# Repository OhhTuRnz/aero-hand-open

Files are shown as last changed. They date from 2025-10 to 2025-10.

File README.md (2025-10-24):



## License — TL;DR

- You **can** integrate Aero Hand units you purchase from TetherIA into **commercial robots and products** you sell.
- **Software (firmware & SDK):** Apache-2.0 — commercial use OK (with notices).
- **Design files (CAD/STEP/STL, drawings, BOM, docs):** CC BY‑NC‑SA 4.0 — **non‑commercial** only; derivatives must use the same license with attribution.
- Want to **manufacture/print parts** or **make your own hands** from our design files for commercial use (spares, kits, or clones)? → **Commercial manufacturing license required**.
- **Commercial licensing & volume buys:** see **LICENSE.md** (or email us at contact@tetheria.ai).

See [**LICENSE.md**](LICENSE.md) for definitions, examples, and contact details.

© 2025 TetherIA Inc. All rights reserved.

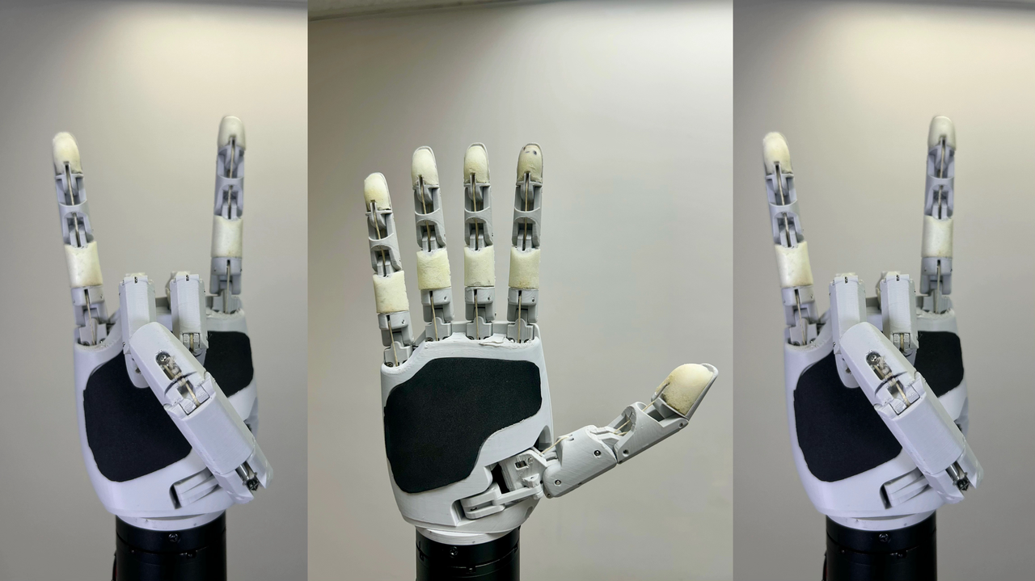
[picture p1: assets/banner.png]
Aero Hand Overview


Aero Hand Open is an **open-source**, **tendon-driven** robotic hand designed and developed by TetherIA for dexterous manipulation research. Unlike expensive proprietary solutions, this hand focuses on **simplicity**, **reliability**, and **accessibility** by using standard 3D printing and off-the-shelf electronic components.

Each joint is optimized for mechanical efficiency through tendon actuation, enabling smooth and natural motion while maintaining a **lightweight** and **compact** design, making it perfect for research labs, educational institutions, and robotics enthusiasts who need an **affordable** yet **capable** manipulation platform.

> **📚 Learn More:** https://docs.tetheria.ai/  
> **🛒 Shop:** https://shop.tetheria.ai/

# Aero Hand Open features:
- 7 DoFs robotic hand with 5 fingers (16 joints in total)
- Tendon-driven architecture for smooth and natural motion
- Fully 3D-printed structure, modular and easy to assemble
- Lightweight design — **389 g**
- Affordable — complete kit for **$314 USD**
- Open-source hardware and firmware
- Independent Python SDK, and compatible with ESP32 and ROS2 systems

# Overview:

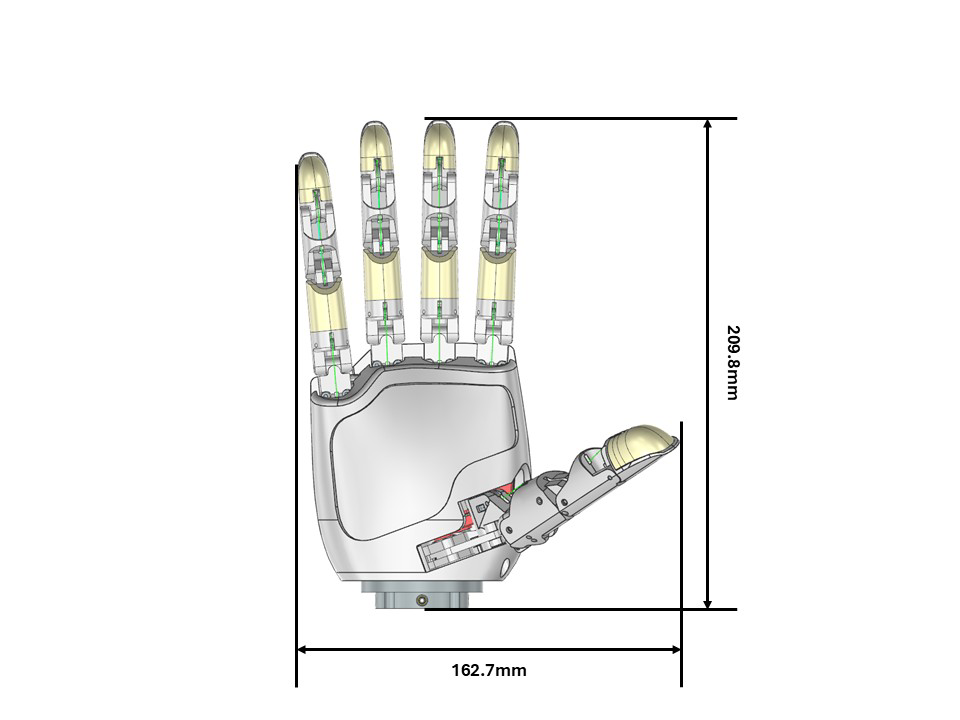
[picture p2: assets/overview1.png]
Overview1


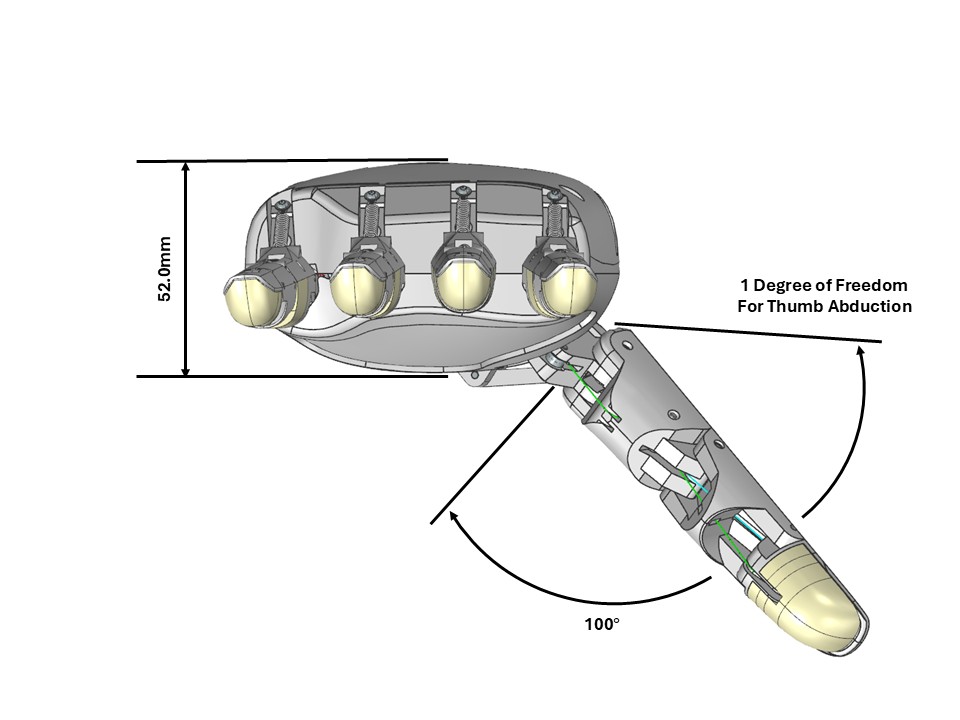
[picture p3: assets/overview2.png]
Overview1


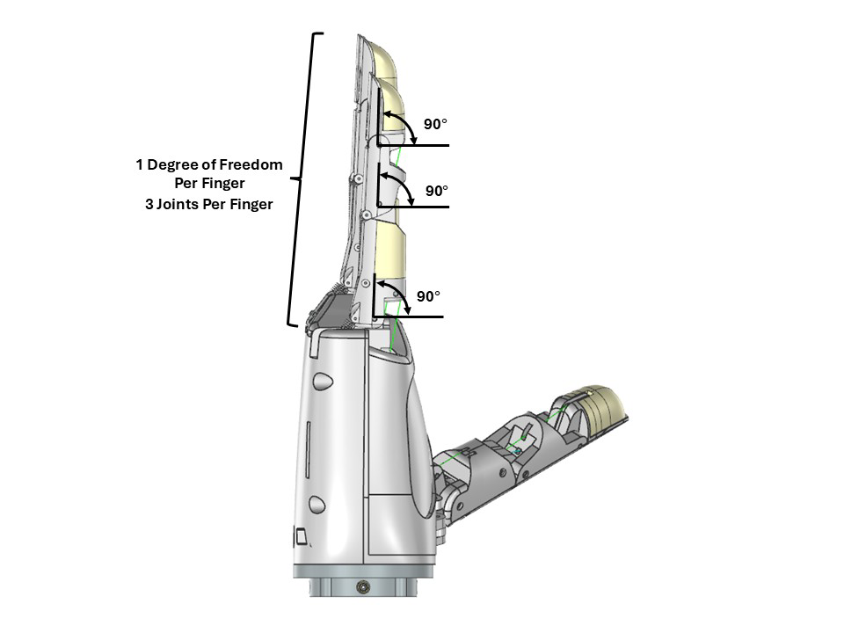
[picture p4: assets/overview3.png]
Overview1


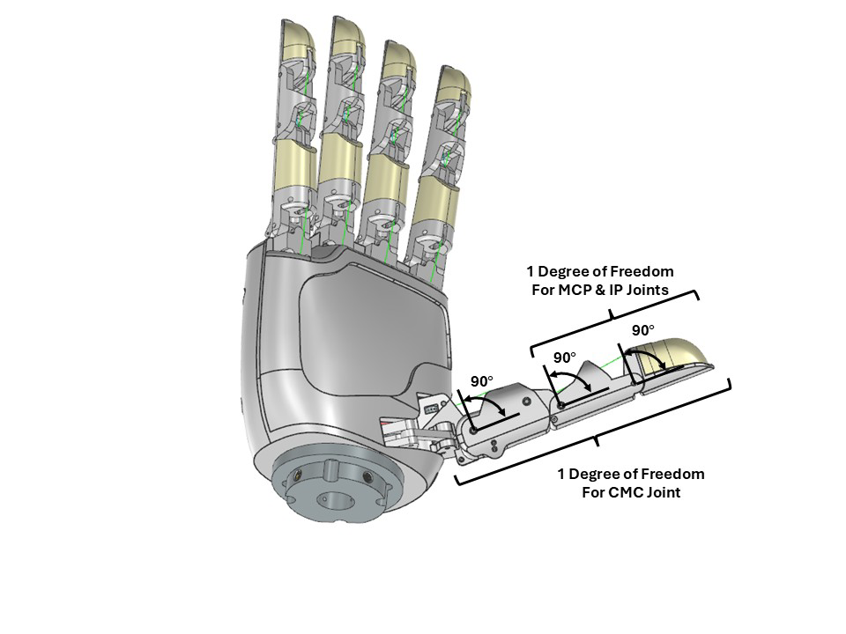
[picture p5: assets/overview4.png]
Overview1


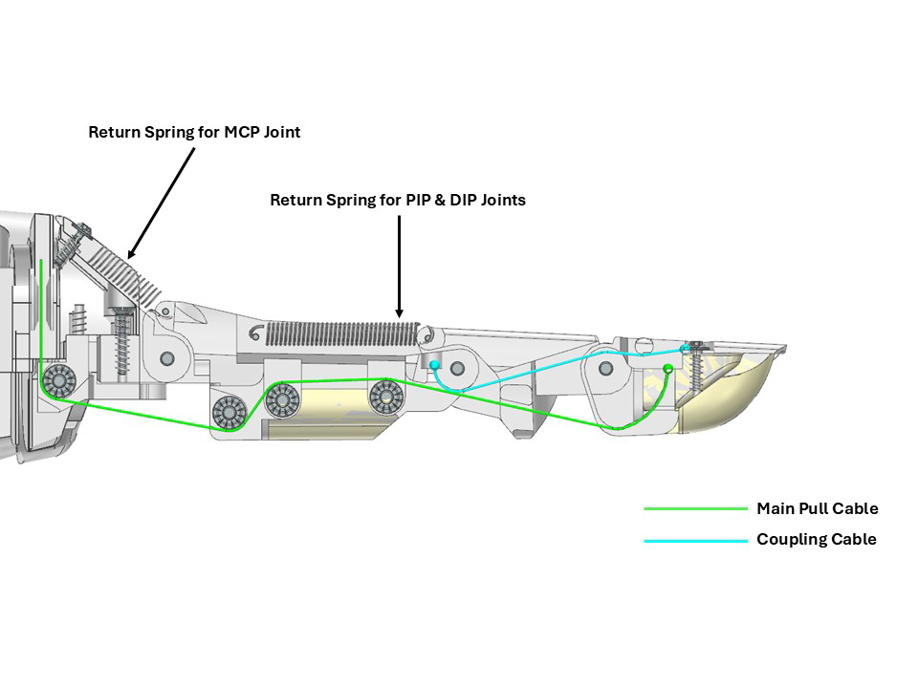
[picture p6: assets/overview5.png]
Overview1


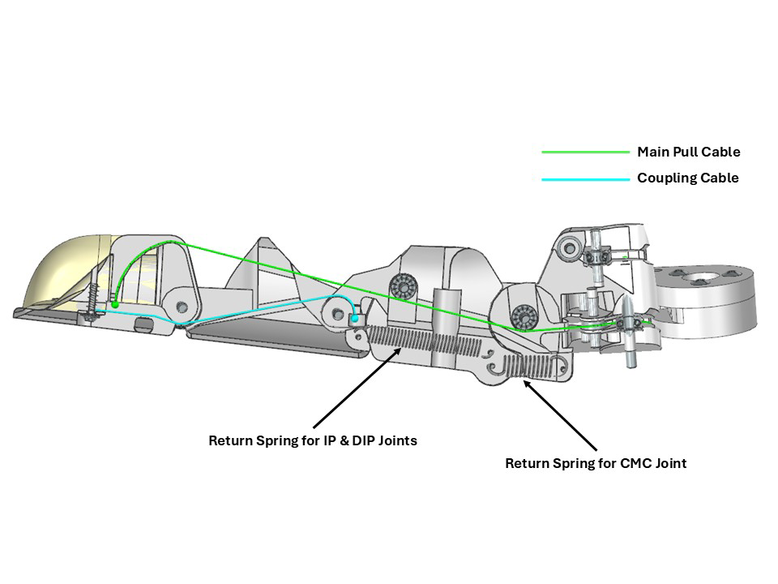
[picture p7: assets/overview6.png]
Overview1


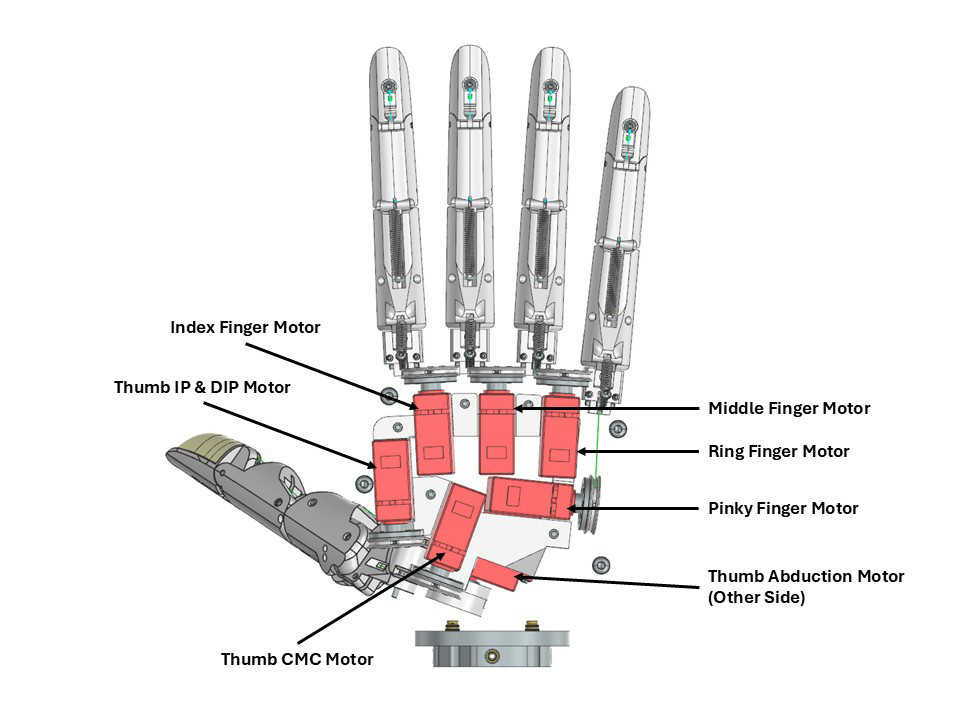
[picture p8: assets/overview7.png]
Overview1


# Table of Contents:
- Resources
  - Bill of Materials (BOM)
  - CAD Files and 3D Models
  - PCB Design
  - Assembly Guide
  - Hardware Setup
  - SDK
  - ROS2 and Teleoperation
- Disclaimer
- Project Updates & Community
  - Updates History
  - FAQ
  - Contact

# Resources
## Bill of Materials (BOM)
The complete list of components required to build Aero Hand Open can be found here:

 [👉 Aero Hand Open – Bill of Materials](./hardware/Assembly/BOM.csv)

This document includes all mechanical, electronic, and printed parts — such as motors, tendons, bearings, fasteners, and 3D-printed components.

Each item is listed with its part number, vendor, quantity, and estimated cost to help you easily source or substitute parts.

## CAD Files and 3D Models
All CAD and 3D model files of Aero Hand Open are available in the [CAD](./hardware/CAD).

You can find both STEP and STL files for modification and direct 3D printing.

> CAD Files Notes:
> The absolute origin of the full assembly is at the MCP joint of middle finger

For quick setup, we also provide a “One-Click Print Pack”, which contains all parts with pre-oriented build angles optimized for print strength, surface quality, and minimal support usage.

Simply load the files into your slicer and start printing — no additional rotation or manual adjustment is required.

Printing Notes:
- Suggested Printer: Bambau Lab X1C/P1S
- Recommended material: PLA (for stiffness and dimensional accuracy)
- Suggested layer height: 0.2 mm (Nozzle Diameter 0.4mm)
- Support: Autogenerate is fine
- The hand design is fully modular — individual fingers can be printed and replaced independently
- Other information can be found in Assembly Documents

An online Onshape model is also available for quick viewing and part reference:

[👉 Aero Hand Open – Onshape Document](https://cad.onshape.com/documents/afc7e0ca7eb6d412ec8771f8/w/bc4d7e45e17e23d622d2bad2/e/1e3862db4d4df7d9dca6f286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)

## Assembly Guide
The step-by-step assembly instructions for Aero Hand Open are provided in the following document:

[👉 Aero Hand Open – Assembly Guide](https://docs.tetheria.ai/docs/assembly)

This guide covers the entire build process, from mounting the actuators to routing the tendons and connecting the electronics. Each finger module can be assembled independently and attached to the palm afterward, allowing easier maintenance and quick replacement.

## PCB Design
The Aero Hand Open consists of two custom PCB boards: Board A and Board B. All design files - including Gerber files, KiCad project files, BOM, and CPL - are available in [PCB folder](./hardware/PCB/)

#### Board A
 - Features 8 Molex connectors for connecting all servos in the hand.
 - Includes a JST connector P3.96mm for outer wiring and fitting inside the hand enclosure.
 - Designed for compact integration and reliable servo connectivity.
#### Board B
 - Includes a JST connector and one Molex connector for testing individual servos and debugging.
 - Features a terminal block to connect a regulated 6V, 10A power supply for the servos.
 - Hosts the ESP32-S3 microcontroller with a USB-C port for:
      - Powering the ESP32-S3
      - Communication between PC and ESP32-S3
      - Interfacing with the hand
 - Board B is essential for diagnostics and safe power delivery.

## Hardware Setup
**Buy our custom PCBs** (described above) from our [website](https://shop.tetheria.ai/products/pcbs) for a **plug-and-play solution**. 

✅ **Benefits:**
- **Zero soldering required** - just plug and play
- **Professional quality** - tested and verified PCBs
- **Self-explanatory connections** - cable connections are straightforward
- **Maximum reliability** - optimized for all motor currents
- **Time-saving** - get your hand running in minutes, not hours

🔗 **[Order PCBs Now →](https://shop.tetheria.ai/products/pcbs)**

For more info please refer to here https://docs.tetheria.ai/docs/hardware_setup

## Software SDK
We provide basic introduction and usage here. A detailed introduction to SDK is included in the following folder.

 👉 [`sdk/README.md`](sdk/README.md)

### Installation: 
📦 Install via pip
```bash
pip install aero-hand-sdk
```
     
🧩 Install from source (editable mode)
Clone the repository to your local machine:
```bash
git clone https://github.com/TetherIA/aero-open-sdk.git
```
     
Navigate to the cloned repository directory:
```bash
cd aero-open-sdk
```

Install the package in editable mode:
```bash
pip install -e .
```

### One-Time Setup
When setting up your hand for the first time, our setup GUI helps you configure motor IDs and test motor connections.
After installation, launch the Setup GUI with:
```bash
aero-hand-gui
```

This provides an interactive interface to configure your hand.

### Sequencing Demo
The Sequencing Demo demonstrates how different finger motions can be combined into continuous, pre-defined sequences.

This script enables users to perform complex gestures — such as pinching, opening the palm, or making a peace sign — by automatically coordinating joint movements in a timed sequence.

You can find the example code in the SDK example folder. 

👉 [`sdk/examples/`](sdk/examples)

Once the SDK is installed and the serial port has been configured, you can run any of the example scripts directly using Python as follows:

```bash
python run_sequence.py
```
[🎥 Watch the demo](assets/sequence_square.mp4)

## ROS2 and Teleoperation
The Aero Hand Open integrates seamlessly with ROS2 humble for advanced robotics applications. The ROS2 package includes:

- **URDF models** for accurate robot simulation and visualization
- **Launch files** for easy integration with existing ROS2 workflows  
- **Teleoperation support** for real-time hand control
- **RViz configuration** for 3D visualization and debugging

Refer to the [`ros2/`](./ros2/) folder for complete setup instructions and examples.

# Disclaimer
Aero Hand Open is an open-source research prototype intended for educational and experimental purposes only.

While every effort has been made to ensure build accuracy and functionality, this design has not been validated for prolonged or heavy-duty use.

Users should exercise caution when assembling, operating, or modifying this device. TetherIA Inc. and its contributors shall not be held liable for any personal injury, property damage, or other losses resulting from the use, misuse, or modification of this design. By using this project, you acknowledge and accept full responsibility for any associated risks.

Important Notes:
- 3D-printed parts may exhibit tolerance variations depending on printer and material settings.
- The tendon-driven mechanism requires regular tension adjustment to maintain consistent motion.
- Overloading the joints or applying excessive torque may cause mechanical deformation or servo damage.
- This project is provided as is, without any warranty or guarantee of fitness for a particular purpose.

We encourage the community to share improvements, feedback, and modifications through pull requests or GitHub discussions.

Your contributions will help make Aero Hand Open more reliable and versatile for the entire robotics community.

# Project Updates & Community
## Updates History
- 10/24/2025
  - Release hardware and ROS2 packages
- 10/13/2025
  - Product launched on all platforms

## FAQ
Q1: Can I modify and redistribute the Aero Hand Open design?

A: Yes, as long as it complies with the CC BY-NC-SA 4.0 license (non-commercial, attribution required, share alike).

Q2: What 3D printer and material do you recommend?

A: Any FDM printer with a ≥200×200 mm bed. PLA works best for strength and dimensional accuracy.

## Contact
For questions, feedback, or collaboration inquiries, please reach out to us through the following channels:

 🛒 Shop: [Aero Hand Open – TetherIA Store](https://shop.tetheria.ai/) 

 📚 Docs: [TetherIA Docs](https://docs.tetheria.ai/)

 📧 Email: support@tetheria.ai

 🌐 Website: [tetheria.ai](http://tetheria.ai)

 🐙 GitHub: [TetherIA](https://github.com/TetherIA)

 💬 Discord: [TetherIA Discord Channel](http://discord.gg/ZQKWK7NebQ)

  🐦 X/Twitter: [TetherIA X/Twitter Account](https://x.com/TetherIA_ai)

  📺 YouTube: [TetherIA YouTube Account](https://www.youtube.com/@TetherIA_ai)

  💼 LinkedIn: [TetherIA LinkedIn Account](https://www.linkedin.com/company/tetheria/)

We welcome discussions, contributions, and new ideas from the community.

If you have improvements to the design, firmware, or control software, feel free to open a Pull Request or start a Discussion on GitHub.

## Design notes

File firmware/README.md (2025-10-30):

<p align="center">
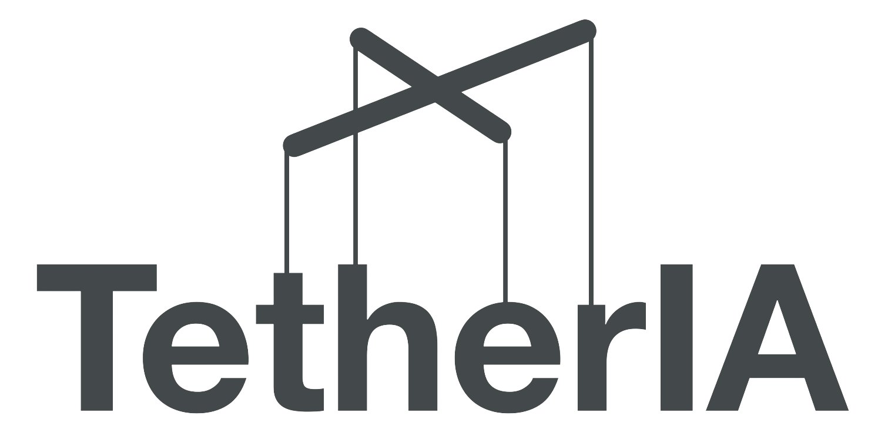
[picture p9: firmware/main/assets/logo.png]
Aero Hand Open by TetherIA
  
  <br/><br/>
</p>

# Aero Hand Open Firmware v0.1.0 — README

A reference guide for building, flashing, using, and extending the **Aero Hand Open** firmware that runs on an ESP32‑S3 (Seeed Studio XIAO ESP32S3) and drives Feetech smart servos - Feetech HLS3606M.

**Note:** If you do not need advanced control over the actuator, you only need the `.bin` file from this repository. You can download the bin files from the `main/bin` folder , and use the GUI to upload them to your device. We recommend using the [aero-open-sdk](https://github.com/TetherIA/aero-open-sdk) to upload the firmware by running the `aero-open-gui`.

---

## Table of Contents
- [1) Overview](#1-overview)
- [2) Repository Layout](#2-repository-layout)
- [3) Hardware & Software Requirements](#3-hardware--software-requirements)
- [4) Quick Start](#4-quick-start)
- [5) Firmware Architecture](#5-firmware-architecture)
- [6) Selecting LEFT vs RIGHT Hand at Build Time](#6-selecting-left-vs-right-hand-at-build-time)
- [7) Serial Protocol](#7-serial-protocol)
- [8) Homing Behavior](#8-homing-behavior)
- [9) Extending the Firmware with a New Command](#9-extending-the-firmware-with-a-new-command)
- [10) Code Reference (quick lookup)](#10-code-reference-quick-lookup)
- [11) Safety & Best Practices](#11-safety--best-practices)
- [12) Troubleshooting](#12-troubleshooting)
- [13) Contribution](#13-contribution)
- [14) License](#14-license)
- [15) Support](#15-Support)

---

## 1) Overview

The firmware exposes a compact **fixed 16‑byte binary serial protocol** so a host PC can command finger positions and query telemetry while the device handles **homing**, calibration, and basic safety on‑board.

**Major components**
- **`firmware_v0.1.0.ino`** — Main sketch: hardware init, serial command parser, periodic tasks, and command handlers.
- **`HandConfig.h`** — **Defines LEFT_HAND or RIGHT_HAND** (build‑time) to select the correct baseline calibration and channel directions.
- **`Homing.h` / `Homing.cpp`** — Implements the **homing** routine (`HOMING_start()` / `HOMING_isBusy()`), plus baseline tables and helpers.

**Servos / channels** (7):
1. Thumb CMC Abduction
2. Thumb CMC Flexion
3. Thumb Tendon (thumb curl/tendon drive)
4. Index
5. Middle
6. Ring
7. Pinky

---

## 2) Repository Layout

```
/main
  ├─ firmware_v0.1.0.ino          # main sketch
  ├─ HandConfig.h                 # LEFT_HAND / RIGHT_HAND selection
  ├─ Homing.h                     # homing API + ServoData type
  ├─ Homing.cpp                   # homing implementation + baselines
  └─ (libraries as needed)
```

---

## 3) Hardware & Software 

- **MCU**: Seeed Studio XIAO ESP32‑S3 (8 MB flash recommended)
- **Servos**: Feetech HLS3606M (IDs mapped to the 7 joints)
- **Power**: Power Servo rail at 6 with adequate current (Max Current up to 10A) , separate from USB 5 V
- **Tools**: [Arduino IDE](https://www.arduino.cc/en/software/) or PlatformIO.

---

## 4) Quick Start

### A. Select LEFT or RIGHT hand
In `HandConfig.h`, **define exactly one** of the following macros, or pass a build flag (see §6):
```c++
// #define LEFT_HAND
#define RIGHT_HAND
```

The choice selects the correct baseline calibration table at build time.

### B. Build & Flash
- **PlatformIO**: On your Visual Studio Code, Once you install the platformIO, Restart your Visual studio Code. You will now see a icon on the left for PlatformIO as below.
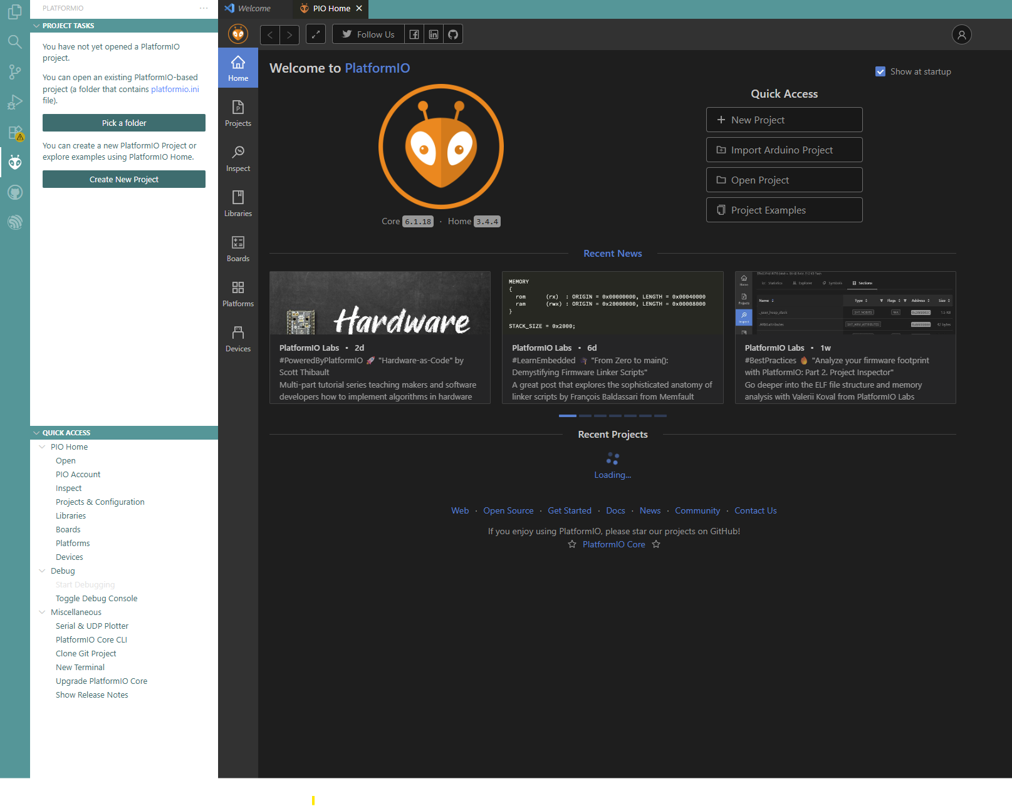
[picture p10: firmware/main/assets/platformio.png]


Once You Reach here, You can press on create a new project . Once you click , It will ask you to enter the Project name and settings, Feel free to choose your desired location and project name,But keep Framework as Arduino and Board as Seeed Studio XIAO ESP32S3.

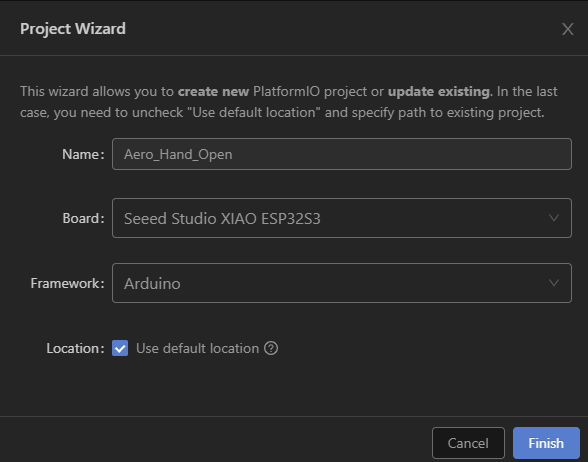
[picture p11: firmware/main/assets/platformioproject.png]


Now it will open the folder with a `platformio.ini` file. You might need to add a location where you have the FTServo library.  You can use build_flags to build it for the right or left hand. You need to copy paste over the ``firmware_v0.1.0.ino`` file in the ``main.cpp`` and you also need the header and cpp files under src directory as in the below given image.

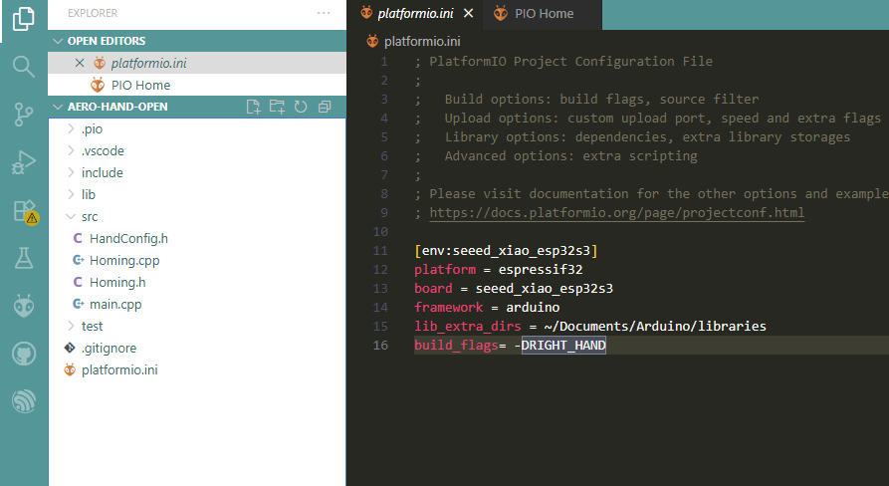
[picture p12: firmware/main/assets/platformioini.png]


Now, You again need to go back to that build and upload page by pressing the PlatformIO icon. Here you can see an upload , Once you press the upload button, It should compile your files and upload it.
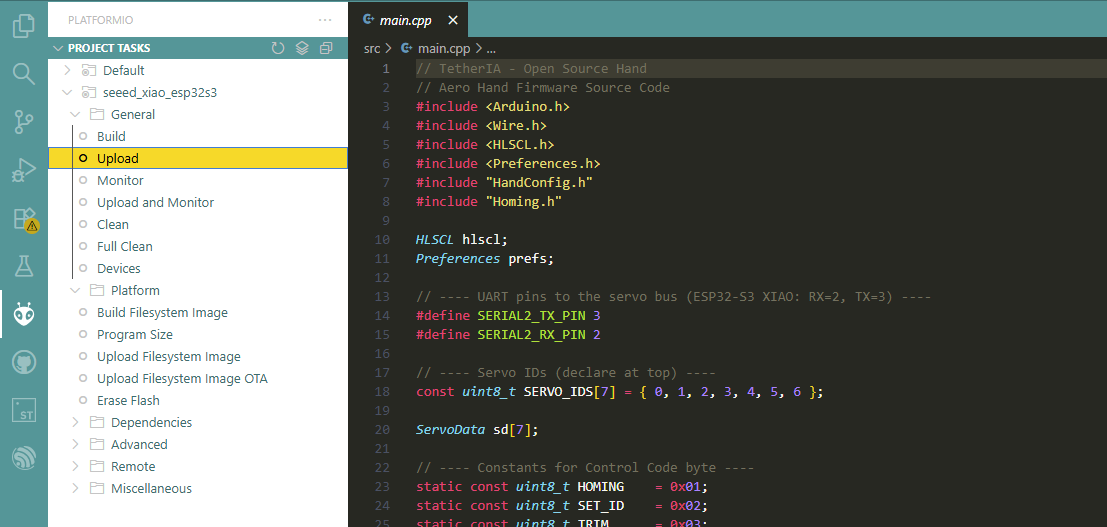
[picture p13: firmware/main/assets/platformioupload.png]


On successful upload, You will see some logs in your terminal window like in the image below.
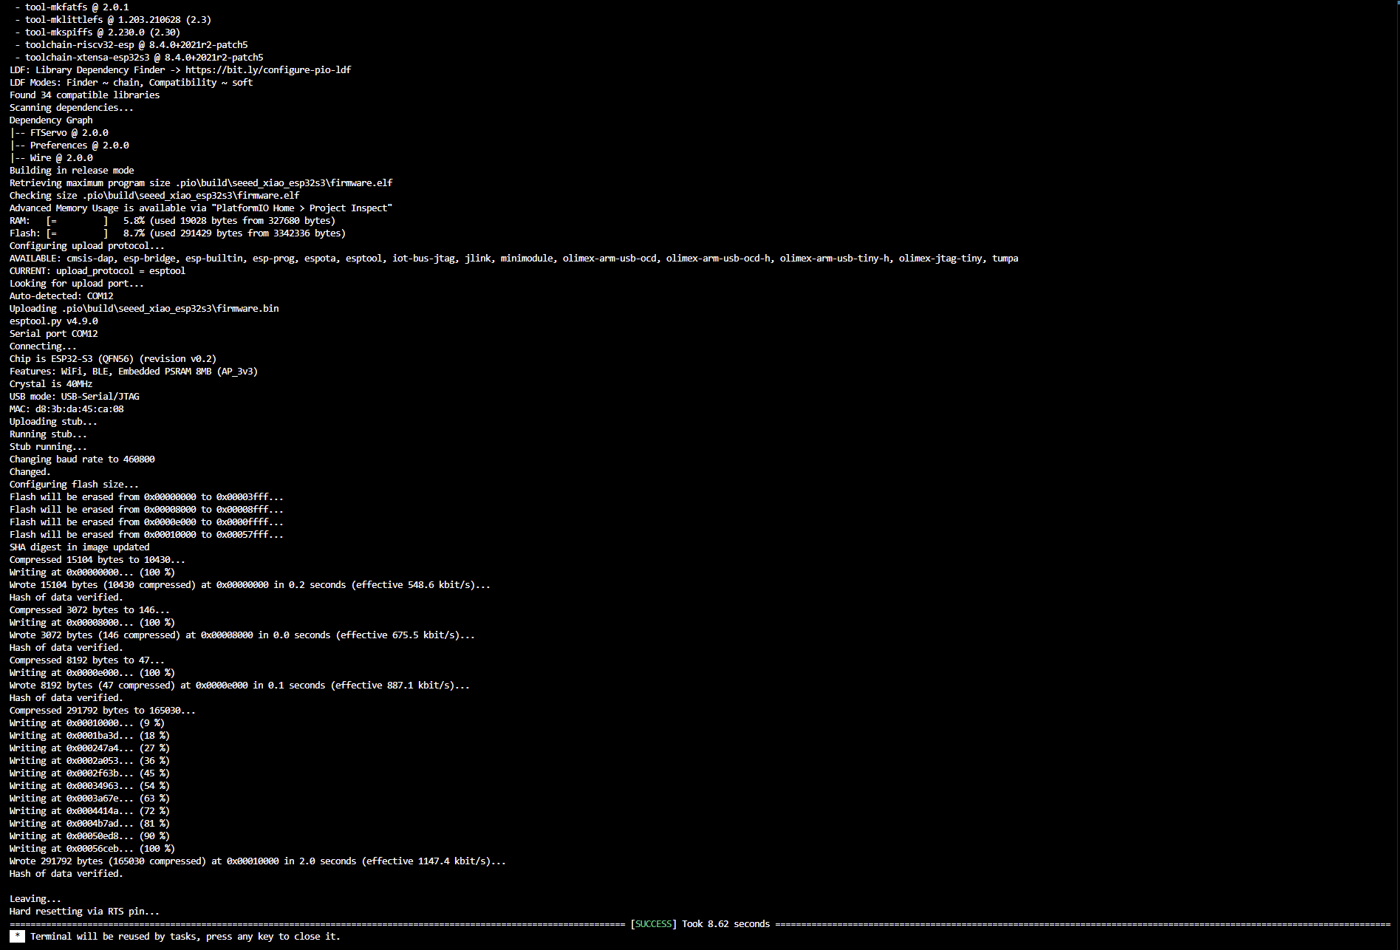
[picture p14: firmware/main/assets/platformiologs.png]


- **Arduino IDE**: open `firmware_v0.1.0.ino`, set Board to *XIAO ESP32S3*, then **Upload**.  
  **Note:** If you are using the Arduino IDE for the first time, you may need to install the ESP32 board support. Go to the Board Manager by pressing Ctrl+Shift+B, then search for "esp32". Find "esp32 by Espressif Systems" and install it. After installation, change the board under the Tools menu and select "XIAO_ESP32S3" from the list.

  

  

### C. First Boot
1. Connect USB, open a serial monitor at the project baud rate (e.g., 1,000,000 or 115,200 as configured - default 921600).
2. On Pressing Reset, Using the Serial monitor make sure that you receive OK from all 7 Servos.

---

## 5) Firmware Architecture

### 5.1 Data structures
- **`ServoData`**: per‑channel configuration `{grasp_count, extend_count, servo_direction}` used to map 16‑bit host commands into per‑servo raw counts (0..4095).
- **Baselines**: compile‑time constants for LEFT and RIGHT hands (7 entries each). A runtime working copy `sd[7]` is initialized from whichever baseline the build selects.

### 5.2 Homing module
- **`HOMING_start()`**: runs the homing routine for all 7 servos.
- **`HOMING_isBusy()`**: returns true while homing is in progress.
- **`resetSdToBaseline()`**: copies the correct baseline into the working array before homing.

### 5.3 Main loop
The main loop performs:
- USB serial polling
- Fast‑path command decode (see §7)
- Optional periodic telemetry sampling and printing

---

## 6) Selecting LEFT vs RIGHT Hand at Build Time

You can switch hands either by editing `HandConfig.h` **or** using build flags.

- **PlatformIO** (`platformio.ini`):
- lib_extra_dirs point to the location where you might need the [FTServo_libraries](https://github.com/ftservo/FTServo_Arduino/tree/main).
- You need to comment both macros of #define LEFT_HAND and #define RIGHT_HAND in ``HandConfig.h``.
- build_flags will help you to build it for the right hand.
  ```ini
  [env:seeed_xiao_esp32s3]
  platform = espressif32
  board = seeed_xiao_esp32s3
  framework = arduino
  lib_extra_dirs = ~/Documents/Arduino/libraries
  build_flags= -DRIGHT_HAND
  ```

- **Arduino IDE**: temporarily uncomment the macro in `HandConfig.h`.

> **Tip:** Keep the default checked into version control (usually `RIGHT_HAND`) and apply overrides via build flags in CI or per‑developer settings.

---

## 7) Serial Protocol

### 7.1 Frame format

### Frame Structure (TX and RX)
| Bytes | Field | Description |
|---|---|---|
| 0 | **Opcode** | Command / response code (e.g., `0x01` for HOMING, `0x04` for TRIM). |
| 1 | **Filler** | Always `0x00` (reserved for future use). |
| 2..15 | **Payload** | 14-byte payload. May contain parameters (channels, degrees, IDs, etc.) or be all zeros in acknowledgments. |

- **All commands from PC → firmware are 16 bytes.**  
- **All responses (ACKs) from firmware → PC are also 16 bytes.**

| Opcode | Name | Direction | Payload (host→device unless noted) | Response (device→host) |
| -----: | --- | --- | --- | --- |
| `0x01` | `HOMING` | H→D | 14 × `0x00` | `[0x01,0x00, 14×0x00]` when complete |
| `0x02` | `SET_ID` | H→D | `new_id(u16)`, `current_limit(u16)`, rest zeros | `[0x02,0x00, oldId(u16), newId(u16), curLim(u16), rest 0]` |
| `0x03` | `TRIM` | H→D | `channel(u16:0..6)`, `degrees(i16: ±360)`, rest zeros | `[0x03,0x00, channel(u16), extendCount(u16), rest 0]` |
| `0x11` | `CTRL_POS` | H→D | **7×** `u16` (channels 0..6). Range `0..65535` maps to **extend→grasp** span per channel. | *(none)* |
| `0x12` | `CTRL_TOR` | H→D | Set torque for all servos (7×u16) | *(none)* |
| `0x22` | `GET_POS`  | H↔D | 14×`0x00` | **7×** `u16` raw positions (counts 0..4095) |
| `0x23` | `GET_VEL`  | H↔D | 14×`0x00` | **7×** `u16` raw velocities |
| `0x24` | `GET_CURR` | H↔D | 14×`0x00` | **7×** `u16` currents |
| `0x25` | `GET_TEMP` | H↔D | 14×`0x00` | **7×** `u16` temperatures (°C or raw, per build) |
| `0x31` | `SET_SPE`  | H→D | `id(u16)`, `speed(u16)`, rest zeros | ACK: id, speed |
| `0x32` | `SET_TOR`  | H→D | `id(u16)`, `torque(u16)`, rest zeros | ACK: id, torque |

Control Modes Note: 
> **Recommendation:** We recommend using position control for typical grasping tasks. Advanced users may use torque control mode, but only when the hand is in a position to grab an object. At higher torque values, if any servo exceeds an internal temperature of 80°C, it may temporarily ignore commands as a safety measure until it cools down.
> **Note:** Torque control is currently implemented in one direction only: from fully open to fully close.

**7.2 Channel Map (0..6)**

0: Thumb CMC Abduction
1: Thumb CMC Flexion
2: Thumb Tendon (curl)
3: Index Finger
4: Middle Finger
5: Ring Finger
6: Pinky Finger 

**7.3 Position Mapping (host 16-bit → servo raw count)**

For each channel i, map host value u16[i] ∈ [0..65535] into raw servo counts using per-channel calibration:

span   = grasp_count[i] - extend_count[i]          // can be ±
raw32  = extend_count[i] + (u16[i] * span) / 65535
raw    = clamp(raw32, 0, 4095)

Direction is handled via servo_direction. Final writes use bus-batched SyncWrite (e.g., SyncWritePosEx) for all 7 servos.

**7.4 Persistence, Homing & Timing**

TRIM updates the extend endpoint for one channel and saves it in NVS (persists across reboots).

HOMING:

Loads baseline tables (LEFT/RIGHT per build flag).

Drives each joint to contact (current-based) to re-establish the open/extend reference.

Blocking: Other commands are ignored until homing finishes and the ACK is issued.

Typical full sequence can take up to ~25 seconds per channel (mechanics-dependent).

GUI “Set to Extend” is a function that sends CTRL_POS with all channels at extend (open). It’s not a separate opcode.

**7.5 Example Frames**

Homing (host→device, then device→host ACK):

```Payload
TX: 01 00 00 00 00 00 00 00 00 00 00 00 00 00 00 00
RX: 01 00 00 00 00 00 00 00 00 00 00 00 00 00 00 00
```

Set ID to 0x0003, current limit 1023 (0x03FF):
```Payload
TX: 02 00 03 00 FF 03 00 00 00 00 00 00 00 00 00 00
RX: 02 00 oldId_lo oldId_hi 03 00 FF 03 00 00 00 00 00 00 00 00
```

Trim channel 3 by −100° (0xFF9C):
```Payload
TX: 03 00 03 00 9C FF 00 00 00 00 00 00 00 00 00 00
RX: 03 00 03 00 ext_lo ext_hi 00 00 00 00 00 00 00 00 00 00
```

CTRL_POS (7 channels). Example: all open (0):
```Payload
TX: 11 00 00 00 00 00 00 00 00 00 00 00 00 00 00 00
(no ACK)
```

GET_TEMP → returns 7×u16 temps:
``` Payload
TX: 25 00 00 00 00 00 00 00 00 00 00 00 00 00 00 00
RX: 25 00 t0_lo t0_hi t1_lo t1_hi ... t6_lo t6_hi
```

**7.6 Bus Access & Robustness**

All sync-read/write paths use a semaphore (e.g., gBusMux) for bus locking to avoid collisions.

Unknown/invalid opcodes are safely ignored to preserve frame alignment.

During HOMING, handlers ignore incoming writes; queue them on the host side.

**7.7 Practical Tips**

Use modest rates (e.g., 50 Hz) for CTRL_POS during validation.

Ensure the servo supply can deliver peak current without droop.

If motion looks inverted, swap extend_count/grasp_count or adjust servo_direction.

To revert large trims, re-run HOMING to restore baselines.

---

## 8) Homing Behavior

The homing routine:
1. Loads the correct baseline via `resetSdToBaseline()`.
2. For each servo, **slowly drives towards a mechanical stop** while monitoring current (a “zero with current” approach).
3. Calibrates offset at contact, performs a small back‑off/settling motion, and finally moves to a defined **extend** posture for consistency across boots.

Timing, current limits, and per‑servo special cases (e.g., thumb tendon) are enforced internally to reduce stress on the mechanism.

> You can safely call `HOMING_start()` at any time from the serial command handler. While homing, ignore position writes or buffer them on the host side.

---

## 9) Extending the Firmware with a New Command

When you want to add a new feature (e.g., LED blink, torque enable/disable, save trim, etc.), follow this pattern:

### Step 1 — Add a new **control byte** (opcode)
At the top of `firmware_v0.1.0.ino`, define a unique `#define` or `static const uint8_t` value not already in use.
```c++
// Example: a simple LED or debug action
static const uint8_t OP_BLINK = 0x42;   // choose a free byte
```

### Step 2 — Implement a handler function
Keep the switch‑case light by moving logic into a small function.
```c++
static void handleBlink(uint8_t count) {
  for (uint8_t i = 0; i < count; ++i) {
    digitalWrite(LED_BUILTIN, HIGH);
    delay(80);
    digitalWrite(LED_BUILTIN, LOW);
    delay(80);
  }
}
```

### Step 3 — Add a `case` in the serial parser
Consume the payload as per use and call the function as per your handler.
```c++
case OP_BLINK: {
  uint8_t count = buf[1];                 // interpret first payload byte
  handleBlink(count);
  break;
}
```

### Step 4 — (Optional) Add a response
If the command should acknowledge or return data, write a 16‑byte response using the same framing convention (byte 0 = response opcode, byte 1 = 0x00, bytes 2..15 = payload).

### Step 5 — Update host tools
If you plan to use our aero-open-hand sdk then you might need to add that functionality under aero_hand.py file.

> **Naming tip:** Use `OP_*` for commands initiated by the host and `RX_*` or `OP_RSP_*` for device responses to avoid confusion.

---

## 10) Code Reference (quick lookup)

### Homing API
```c++
bool HOMING_isBusy();
void HOMING_start();
void resetSdToBaseline();
```

### Servo configuration
```c++
struct ServoData {     // one per channel
  uint16_t grasp_count;    // closed endpoint (raw 0..4095)
  uint16_t extend_count;   // open endpoint  (raw 0..4095)
  int8_t   servo_direction; // +1 or -1 direction convention
};
```

### Build‑time hand selection
```c++
// In HandConfig.h: define exactly one
// #define LEFT_HAND
// #define RIGHT_HAND
```

---

## 11) Safety & Best Practices
- Start with **low speeds/torque** when testing new code.
- Ensure the servo supply can deliver peak current without large droops.
- Keep cable lengths short and bus terminations clean; avoid ground loops.
- Avoid sending high‑rate position frames during homing.

---

## 12) Troubleshooting
- **Wrong hand geometry**: Verify your build flags (`-DLEFT_HAND` vs `-DRIGHT_HAND`).
- **Servos drive the wrong way**: Check `servo_direction` for the affected channel or swap extend/grasp counts.
- **Homing stalls**: Inspect current limits/timeouts; make sure mechanics move freely.
- **No serial activity**: Confirm port, baud rate, and that frames are exactly 16 bytes with the correct opcode.

---

## 13) Contribution
We welcome community contributions!

If you would like to improve the Firmware or add new features:

1. Fork and create a feature branch.
2. Add or modify opcodes and handlers as described in Section 9.
3. Include brief unit/bench tests where possible.
4. Commit your changes with clear messages.
5. Push your branch to your fork.
6. Open a PR with a summary and scope of changes.

---

## 14) License
This project is licensed under **Apache License 2.0**

---

## 15) Support 
If you encounter issues or have feature requests:
- Open a [GitHub Issue](https://github.com/TetherIA/aero-open-sdk/issues)
- Contact us at **contact@tetheria.ai**

---

<div align="center">
**Happy building!** Try something new, break things safely, and share what you learn.
If you find this project useful, please give it a star! ⭐

Built with ❤️ by TetherIA.ai
</div>

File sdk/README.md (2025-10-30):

<p align="center">
  Aero Hand Open by TetherIA
  <br/><br/>
</p>

<div align="center">








</div>

<h2 align="center">
  <p>Aero Hand SDK — Python Interface for TetherIA's Robotic Hand</p>
</h2>

<div align="center">
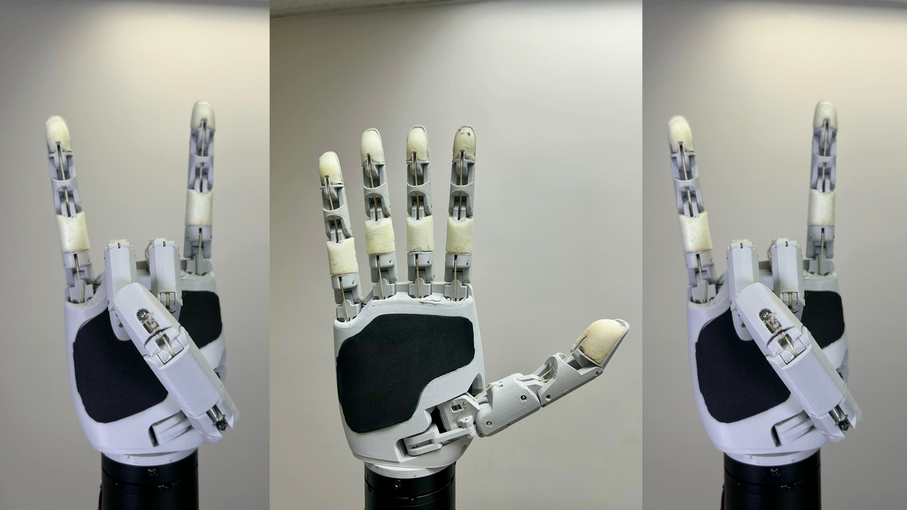
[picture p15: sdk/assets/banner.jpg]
Aero Hand Demo Aero Hand in action
  
  <p><strong>Aero Hand Open</strong> is a 7-DoF tendon-driven robotic hand for dexterous manipulation and research.</p>
  <p>The SDK enables full control via Python. Perform homing, calibration, and precise motion control with ease.</p>
</div>

---

## ⚙️ Installation

The SDK is currently tested for Python 3.10 and above.

### 📦 Install via pip

```bash
pip install aero-hand-sdk
```

### 🧩 Install from source (editable mode)

1. Clone the repository to your local machine:
   ```bash
   git clone https://github.com/TetherIA/aero-open-sdk.git
   ```

2. Navigate to the cloned repository directory:
   ```bash
   cd aero-open-sdk
   ```

3. Install the package in editable mode:
   ```bash
   pip install -e .
   ```

---

## 🖥️ One-Time Setup

When setting up your hand for the first time, our setup GUI helps you configure motor IDs and test motor connections.

After installation, launch the Setup GUI with:

```bash
aero-open-gui
```

This provides an interactive interface to configure your hand.

---

## 🔌 Serial Port Setup

Aero Hand connects to the host PC via a serial (USB) interface.
To operate the SDK, you must specify the correct serial port for your device.

### 🐧 Linux

Most Linux systems assign the device path as `/dev/ttyACM0` or `/dev/ttyUSB0`. You can list connected serial devices with:

```bash
ls /dev/ttyACM* /dev/ttyUSB*
```

**💡 Persistent Device Path (Recommended)**

Device names like `/dev/ttyUSB0` can change each time you reconnect.

To get a persistent name, use the by-id symlink instead:

```bash
ls -l /dev/serial/by-id/
```

This will show you a list of connected serial devices with more descriptive names. Look for the one that corresponds to your Aero Hand. Which will look something like:
```bash
usb-Espressif_USB_JTAG_serial_debug_unit_D8:3B:DA:45:C8:1C-if00
```
Then initialize your hand using that path:
```python
from aero_open_sdk.aero_hand import AeroHand

aero_hand = AeroHand(
  port="/dev/serial/by-id/usb-Espressif_USB_JTAG_serial_debug_unit_D8:3B:DA:45:C8:1C-if00"
)
```
✅ This ensures your connection always points to the correct device, even if you unplug and replug the hand or change the USB port.

### 🪟 Windows
On Windows, the device will appear as a COM port like `COM3` or `COM4`. You can find the correct COM port by checking the Device Manager under "Ports (COM & LPT)".

You can then Initialize your hand with the detected COM port:
```python
from aero_open_sdk.aero_hand import AeroHand
aero_hand = AeroHand(port="COM3")
```
**💡 Making the COM Port Persistent**

Windows does not have a /by-id/ system like Linux, so the COM number can change if you plug the device into a different USB port.

To make it permanent, you can assign a fixed COM number:
1. Plug in the Aero Hand and open Device Manager.
2. Find it under Ports (COM & LPT).
3. Right-click → Properties → Port Settings → Advanced.
4. In COM Port Number, select an unused port (e.g., COM5).
5. Click OK to save.

You can now always use this COM port when initializing the SDK.

---

## 💡 Examples

To integrate the SDK into your own code, refer to the `examples` folder for sample files demonstrating basic usage.

---

## 🧰 Troubleshooting

### 1. Installation Fails (`pip install` error)

If installation fails, try the following steps:

- Check your Python version:

    Make sure you have Python 3.10 or higher installed.

- 🔧 Upgrade pip to the latest version:

    Our package requires an up-to-date version of pip.

    You can upgrade pip with:
    ```bash
    pip install --upgrade pip
    ```

On Windows, if you see error like "pip is not recognized", use the `py` launcher command instead:

    ```bash
    py -m pip install --upgrade pip
    ```

### 2. Path Mismatch on Windows

- You may not have the Python Scripts path added to your system PATH environment variable.

- To fix this, you can either:

  1. Add the Python Scripts directory (e.g., `C:\Users\<YourName>\AppData\Local\Programs\Python\Python310\Scripts`) to your system PATH.
  2. Or use the `py` launcher command to launch the GUI after installation:
      ```bash
      py -m aero_open_sdk
      ```
  3. Create a virtual environment and install the package there.
      ```bash
      python -m venv venv
      .\venv\Scripts\activate
      pip install aero-open-sdk
      aero-open-gui
      ```

### 3. Linux Troubleshooting: Serial Port Permission

If you see a permission error when connecting to the serial port (e.g., `/dev/ttyACM0`), do the following:

1. Find your username:
   ```sh
   whoami
   ```
2. Add your user to the `dialout` group (replace `yourusername` with the output from `whoami`):
   ```sh
   sudo usermod -a -G dialout yourusername
   ```
3. **Restart your system** (or log out and log back in).
4. After restart, open a terminal and run:
   ```sh
   groups
   ```
   You should see your username and `dialout` listed.
5. Try connecting to the serial port again in the GUI.

If you still see permission errors, check device permissions with:
```sh
ls -l /dev/ttyACM0
```
You may need to temporarily set permissions:
```sh
sudo chmod 666 /dev/ttyACM0
```

## 💬 Support

If you encounter issues or have feature requests:
- Open a [GitHub Issue](https://github.com/TetherIA/aero-open-sdk/issues)
- Contact us at **contact@tetheria.ai**

---

## 🤝 Contribution

We welcome community contributions!

If you'd like to improve the SDK, fix bugs, or add new features:

1. Fork this repository.
2. Create a new branch for your changes.
    ```bash
    git checkout -b feature/your-feature-name
    ```

3. Commit your changes with clear messages.

4. Push your branch to your fork.

5. Open a Pull Request (PR) describing your updates.

---

## ⚖️ License

This project is licensed under the **Apache License 2.0**.

<div align="center">
If you find this project useful, please give it a star! ⭐

Built with ❤️ by TetherIA.ai
</div>

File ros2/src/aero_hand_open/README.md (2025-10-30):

# 🤖 Aero Hand Open ROS 2 Node

The **Aero Hand Open Node** provides a ROS 2 interface for controlling TetherIA’s [Aero Hand](https://github.com/TetherIA/aero-open-sdk) via the **Aero Hand SDK**.  
It allows controlling one or both hands simultaneously, exposing ROS 2 topics for both **joint-space** and **actuator-space** control.

## 🧩 Overview

This node acts as a bridge between ROS 2 and the Aero Hand hardware. It:
- Accepts commands for **joint angles** or **actuator positions**.
- Publishes real-time **actuator state feedback** (positions, speeds, currents, temperatures).
- Supports **single-hand** (right/left) or **dual-hand** operation.
- Uses parameters for serial ports, baud rate, and control mode.

## ⚙️ Running the Node

```bash
ros2 run aero_hand_open aero_hand_node
```

### Parameters

| Parameter | Type | Default | Description |
|---|---|---|---|
| `right_port` | `string` | `""` | Serial port for the right hand |
| `left_port` | `string` | `""` | Serial port for the left hand |
| `baudrate` | `int` | `921600` | Serial baud rate |
| `feedback_frequency` | `float` | `100.0` | Rate (Hz) to publish actuator feedback |
| `control_space` | `string` | `"joint"` | Control mode: `"joint"` or `"actuator"` |

Example run:
```bash
ros2 run aero_hand_open aero_hand_node --ros-args -p right_port:=/dev/ttyUSB0 -p left_port:=/dev/ttyUSB1 -p control_space:=joint
```

## 🛰️ ROS 2 Interfaces

### Subscribed Topics

| Topic | Message Type | Description |
|---|---|---|
| `right/joint_control` | `aero_hand_open_msgs/JointControl` | Right hand joint-angle commands (radians) |
| `left/joint_control` | `aero_hand_open_msgs/JointControl` | Left hand joint-angle commands (radians) |
| `right/actuator_control` | `aero_hand_open_msgs/ActuatorControl` | Right hand actuator-space commands |
| `left/actuator_control` | `aero_hand_open_msgs/ActuatorControl` | Left hand actuator-space commands |

> Only one control mode is active at a time, based on `control_space`.

### Published Topics

| Topic | Message Type | Description |
|---|---|---|
| `right/actuator_states` | `aero_hand_open_msgs/ActuatorStates` | Feedback for the right hand |
| `left/actuator_states` | `aero_hand_open_msgs/ActuatorStates` | Feedback for the left hand |

## 🧠 Behavior Summary

- **Initialization:**  
  Each hand is initialized if a valid serial port is provided.  
  The node throws an error if both `right_port` and `left_port` are empty.

- **Feedback:**  
  At the configured rate, the node publishes:
  - `actuations`
  - `actuator_speeds`
  - `actuator_currents`
  - `actuator_temperatures`

## 🧩 Dependencies

- **ROS 2 Humble** (or newer)
- **aero_open_sdk**
- **aero_hand_open_msgs**

Make sure the SDK is installed and accessible in your environment.

---

## ⚖️ License

This project is licensed under the **Apache License 2.0**.

---

<div align="center">
If you find this project useful, please give it a star! ⭐  

Built with ❤️ by <a href="https://tetheria.ai">TetherIA.ai</a>
</div>

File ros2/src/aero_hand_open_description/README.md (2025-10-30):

# 🦾 Aero Hand Open Description — ROS 2 Package

The **Aero Hand Open Description** package provides the 3D model, URDF, and visualization configuration for **TetherIA’s Aero Hand Open** — a 7-DoF tendon-driven robotic hand designed for research and dexterous manipulation.  

---

## 🧩 Overview

This package contains:
- ✅ **URDF and meshes** for the right and left Aero Hand Open models.  
- ⚙️ **Launch files** for quick visualization in RViz.  

## ⚙️ Launch File: `display.launch.py`

This launch file loads the URDF model, publishes its joint states, and visualizes it in RViz.  

### Example Usage

```bash
ros2 launch aero_hand_open_description display.launch.py
```

## 🧪 Visualization Workflow

1. Launch RViz using this package:
   ```bash
   ros2 launch aero_hand_open_description display.launch.py
   ```
2. Move sliders in the **joint_state_publisher_gui** window to manipulate finger joints.
3. Observe the live visualization in RViz.

You can also remap the topic `/joint_states` or connect it to a live controller node (e.g., from `aero_hand_open` or `aero_hand_open_teleop`).

---

## ⚖️ License

This project is licensed under the **Apache License 2.0**.

---

<div align="center">
If you find this project useful, please give it a star! ⭐  

Built with ❤️ by <a href="https://tetheria.ai">TetherIA.ai</a>
</div>

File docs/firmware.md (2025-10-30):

# Firmware

This guide covers architecture, build options, and a detailed communication protocol specification used by the **ESP32‑S3 (Seeed Studio XIAO ESP32S3)** to drive **Feetech HLS3606M servos**.

---

## 🧭 Overview

The firmware exposes a compact **fixed 16‑byte binary serial protocol** for commanding seven actuators (thumb & fingers) and for querying telemetry (position, velocity, current, temperature). It also implements **homing**, **set-id**, **persistent trims**, and safety behaviors on‑board, so a host PC can remain simple.

**Channels (7):**

1. Thumb CMC Abduction Actuator
2. Thumb CMC Flexion Actuator
3. Thumb Tendon Actuator
4. Index Finger Actuator 
5. Middle Finger Actuator
6. Ring Finger Actuator
7. Pinky Finger Actuator

---

## 🧰 Hardware & Software Requirements

* **MCU:** Seeed Studio XIAO ESP32‑S3 (8 MB flash recommended)
* **Servos:** Feetech HLS/SC family (e.g., HLS3606M), IDs mapped to 7 actuators
* **Power:** Servo rail 6–9 V with adequate current capacity; USB-C 5 V for MCU. We recommend a stable power supply at 6V for driving the hand capable of delivering upto 10A.
* **Tools:** Arduino IDE **or** PlatformIO

---

## ⚡ Quick Start

1. **Select the hand** (left/right) in `HandConfig.h` or via a build flag (see below).
2. **Build & flash:**
   * **PlatformIO:** choose `seeed_xiao_esp32s3` ➜ **Upload**
   * **Arduino IDE:** open main sketch ➜ set board to **XIAO ESP32S3** ➜ **Upload**
3. **First boot:** open a serial monitor at the configured baud (commonly 921600 or 1 000 000). Verify the board enumerates and servos respond OK if power is connected.

---

## 📁 Repository Layout

```
/firmware
  ├─ firmware_v0.1.0.ino         # Main sketch: init, parser, handlers, tasks
  ├─ HandConfig.h                # LEFT_HAND / RIGHT_HAND selection
  ├─ Homing.h                    # Homing API + ServoData type
  ├─ Homing.cpp                  # Homing implementation + baselines
  └─ libraries/                  # Third‑party libraries as needed
```

---

## 🔁 Build Configuration: Left vs Right Hand

You can switch hands either by editing `HandConfig.h` **or** using build flags.

* **PlatformIO** (`platformio.ini`):

  ```ini
  [env:seeed_xiao_esp32s3]
  platform = espressif32
  board = seeed_xiao_esp32s3
  framework = arduino
  build_flags = -DRIGHT_HAND       ; or -DLEFT_HAND
  ```
* **Arduino IDE:** temporarily uncomment the macro in `HandConfig.h`.

> Tip: Keep a default committed (often `RIGHT_HAND`) and override via CI or local flags when building the opposite hand.
> Note: You can also use the aero-hand-gui to upload a bin file directly onto the ESP32S3 without using any of this software.

---

## 🔌 Communication Protocol

The protocol is **always 16 bytes** per frame, both **to** and **from** the device. Payload words are **little‑endian**.

### Frame Format

| Bytes | Field | Description |
| ----: | --- | --- |
| 0 | **OPCODE**  | Command / request code |
| 1 | **FILLER**  | Always `0x00` (reserved) |
| 2..15 | **PAYLOAD** | 14‑byte payload; semantics depend on opcode |

> **ACK/Responses** also use the same 16‑byte frame shape; byte 0 contains the response opcode, byte 1 is `0x00`.

### Opcode Reference

> The table below is the canonical mapping used by this firmware version.

| Opcode | Name | Direction | Payload (PC→Device unless noted)  | Notes |
| :----: | --- | :---: | --- | --- |
| `0x01` | **HOMING** | PC→Dev  | none (payload = zeros) | Runs full homing & calibration; blocks other commands until complete; returns an ACK. |
| `0x02` | **SET_ID** | PC→Dev  | `u16 new_id`, `u16 current_limit` | Scans bus for the single attached servo, sets its ID and current limit; returns an ACK with old/new ID and limit. |
| `0x03` | **TRIM** | PC→Dev  | `u16 channel`, `s16 degrees_off`  | Adjusts stored **extend_count** for a channel; persists in NVS; returns an ACK with the resulting extend count. |
| `0x11` | **CTRL_POS** | PC→Dev  | 7×`u16` (ch0..ch6) | Position write for all channels. 0..65535 spans each channel’s **extend ↔ grasp**. No ACK (fire‑and‑go). |
| `0x12` | **CTRL_TOR** | PC→Dev  | 7x`u16` (ch0..ch6) | Torque write for all channels. 0..1000 is the limit for setting torque to each servo in direction **extend ↔ grasp** . No ACK (fire-and-go) |
| `0x22` | **GET_POS**  | PC→Dev  | none | Device replies with 7×`u16` raw positions. |
| `0x23` | **GET_VEL**  | PC→Dev  | none | Device replies with 7×`u16` velocities. |
| `0x24` | **GET_CURR** | PC→Dev  | none | Device replies with 7×`u16` currents. |
| `0x25` | **GET_TEMP** | PC→Dev  | none | Device replies with 7×`u16` temperatures. |
| `0x31` | **SET_SPE**  | PC→Dev  | `u16 id`, `u16 speed_limit` | Sets the speed limit for the specified servo ID. |
| `0x32` | **SET_TOR**  | PC→Dev  | `u16 id`, `u16 torque_limit` | Sets the maximum torque for the specified servo ID (different from torque control; this is a limit, not a command).|

#### Position Mapping (CTRL_POS)

For each channel *i*, the firmware maps host value `u16[i]∈[0,65535]` linearly to the servo’s raw count using the per‑channel `extend_count` (open) and `grasp_count` (closed), clamped to `[0,4095]`. Direction is handled via `servo_direction`.

#### Torque Control (CTRL_TOR)

For each channel, the firmware maps the incoming torque value in the range 0..1000 linearly to the raw torque sent to the servo, applying it only in the direction from extend to grasp.

#### Example Sequences

* **Homing**
  PC → Dev: `[0x01, 0x00, 14×0x00]`
  Dev homes all servos → Dev → PC: `[0x01, 0x00, 14×0x00]`

* **Trim channel 3 by −100°**
  PC → Dev: `[0x03, 0x00, 0x03,0x00, 0x9C,0xFF, 10×0x00]`
  Dev updates extend count & saves to NVS → Dev → PC: `[0x03, 0x00, 0x03,0x00, ext_lo,ext_hi, rest 0]`

> **Framing robustness:** Unrecognized opcodes are consumed/ignored to maintain alignment; malformed frames are dropped.

---

## 🧱 Firmware Architecture

### Data Structures

```c++
struct ServoData {              // one per channel
  uint16_t grasp_count;         // closed endpoint (0..4095)
  uint16_t extend_count;        // open endpoint  (0..4095)
  int8_t   servo_direction;     // +1 or −1
};
```

* **Baselines:** compile‑time constants for LEFT and RIGHT hands (7 entries each). A runtime working copy `sd[7]` is refreshed from the baseline (e.g., at boot or before homing).

### Homing Module

* `HOMING_start()` — runs the homing routine for all servos.
* `HOMING_isBusy()` — returns `true` while homing is in progress.
* `resetSdToBaseline()` — copies the correct baseline values into `sd[7]`.

### Concurrency & I/O

* **Bus locking:** all sync read/write operations acquire a semaphore (e.g., `gBusMux`) to prevent collisions.
* **Persistence:** trims (extend counts) are stored in **NVS** so they survive reboots; a full **HOMING** reset returns to baseline.
* **Telemetry:** batched `SyncRead` used for GET_*; CSV printing (if enabled) multiplexed through a single serial writer.

---

## 🧰 Homing Behavior

1. Load the appropriate baseline via `resetSdToBaseline()`.
2. For each servo, drive slowly toward a mechanical stop while monitoring current to detect contact.
3. Calibrate the offset at contact, back‑off/settle, then move to a consistent **extend** posture.

**Notes:** Homing may take around a minute or two overall since each servo is given a timeout of 25s to find a hard mechanical stop in a given direction. During homing, other commands are ignored (buffer on the host if needed), So it will wait for an ACK for a given time period.

---

## 🧩 Extending the Firmware (Add a New Command)

Follow this pattern to add features like LED blink, torque enable, or special saves.

**Step 1 — Define a new opcode**

```c++
static const uint8_t OP_BLINK = 0x42;   // choose an unused byte
```

**Step 2 — Implement a small handler**

```c++
static void handleBlink(uint8_t count) {
  for (uint8_t i = 0; i < count; ++i) {
    digitalWrite(LED_BUILTIN, HIGH); delay(80);
    digitalWrite(LED_BUILTIN, LOW);  delay(80);
  }
}
```

**Step 3 — Wire it into the parser**

```c++
case OP_BLINK: {
  uint8_t count = payload[0];   // interpret first payload byte
  handleBlink(count);
  break;
}
```

**Step 4 — (Optional) ACK**
Return a 16‑byte response if the host should be notified of completion or status.

**Step 5 — Update host tools**
Extend your Python SDK/GUI (e.g., `aero_hand.py`) to emit and consume the new opcode.

---

## 🔐 Safety & Best Practices

* Start with conservative speeds/torque when testing.
* Ensure the servo supply can deliver peak current without large drops.
* Avoid high‑rate position writes during homing.
* Use `HOMING` to re‑establish known geometry if trims become inconsistent.
* Always check power if the servos are not moving.

---

## 🧯 Troubleshooting

* **Wrong hand geometry:** Verify build flag (`-DLEFT_HAND` vs `-DRIGHT_HAND`).
* **Servos move opposite:** Check `servo_direction` or swap extend/grasp counts. We recommend not to change the servo_direction , extend_count can be changed by Trim Servo.
* **Homing stalls:** Inspect current limits/timeouts; verify mechanics move freely.
* **No serial activity:** Confirm COM port/baud and that frames are exactly 16 bytes with valid opcodes.

---

## 📄 License

This project is licensed under **Apache License‑2.0** 

---
## 🤝 Contribution

We welcome community contributions!

If you would like to improve the [Firmware](https://github.com/TetherIA/aero-open-firmware) or add new features:

1. Fork and create a feature branch.
2. Add or modify opcodes and handlers as described in Section 9.
3. Include brief unit/bench tests where possible.
4. Commit your changes with clear messages.
5. Push your branch to your fork.
6. Open a PR with a summary and scope of changes.

---

## 🤝 Support & Contact

* Open a GitHub Issue on the project repository
* Email: **[contact@tetheria.ai](mailto:contact@tetheria.ai)**

<div align="center">

Made with ❤️ by **TetherIA Robotics**

</div>

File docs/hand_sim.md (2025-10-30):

# Sim and RL

The **TetherIA Aero Hand Open** features a physically accurate **tendon-driven actuation system** that emulates real cable mechanics, allowing control and observation directly in **tendon space**. This design provides a faithful bridge between simulation and real-world deployment.

The hand can be simulated across multiple physics platforms. Currently, it supports the **[MuJoCo simulator](https://mujoco.org/)**, where it is fully integrated into **[MuJoCo Playground](https://github.com/google-deepmind/mujoco_playground)** for seamless visualization, training, and evaluation of tendon-space control policies. Support for additional simulation platforms is currently in progress.

- **Hand Model:** [MuJoCo Menagerie – TetherIA Aero Hand Open](https://github.com/TetherIA/mujoco_menagerie/tree/main/tetheria_aero_hand_open)  
- **Training Tools:** [MuJoCo Playground](https://github.com/TetherIA/mujoco_playground_pr)

---

## 🚀 Quick Start

If you’d like to **train your own policy**, follow these steps:

1. Install **MuJoCo Playground** following the [installation guide](https://github.com/TetherIA/mujoco_playground_pr/blob/main/README.md).  
2. Try the built-in **Z-axis rotation environment** for a quick demo, or create your own custom task following [this example](https://github.com/TetherIA/mujoco_playground_pr/blob/main/mujoco_playground/_src/manipulation/aero_hand/rotate_z.py).  
3. Launch training with:

```bash
python learning/train_jax_ppo.py --env_name AeroCubeRotateZAxis
```
You can replace `AeroCubeRotateZAxis` with the name of your own environment. After training, a rollout video will be saved as `rollout0.mp4`.

If you'd like to explore TetherIA Aero Hand Open within the MuJoCo simulator, follow these steps:

1. Follow the [official MuJoCo installation guide](https://mujoco.readthedocs.io/en/latest/programming/#getting-started).
2. The hand model is hosted under our fork of the MuJoCo Menagerie:
   ```bash
      git clone git@github.com:TetherIA/mujoco_menagerie.git
   ```
3. Navigate to the hand’s directory and open the simulation scene:
   ```bash
      cd mujoco_menagerie/tetheria_aero_hand_open
      simulate scene_right.xml
   ```

**Main features include:**
- Physically consistent tendon routing and pulley mechanics.  
- Full tendon-space control and observation interface.  
- JAX-based PPO training integrated with MuJoCo Playground.  

An overview of the hand is shown below:

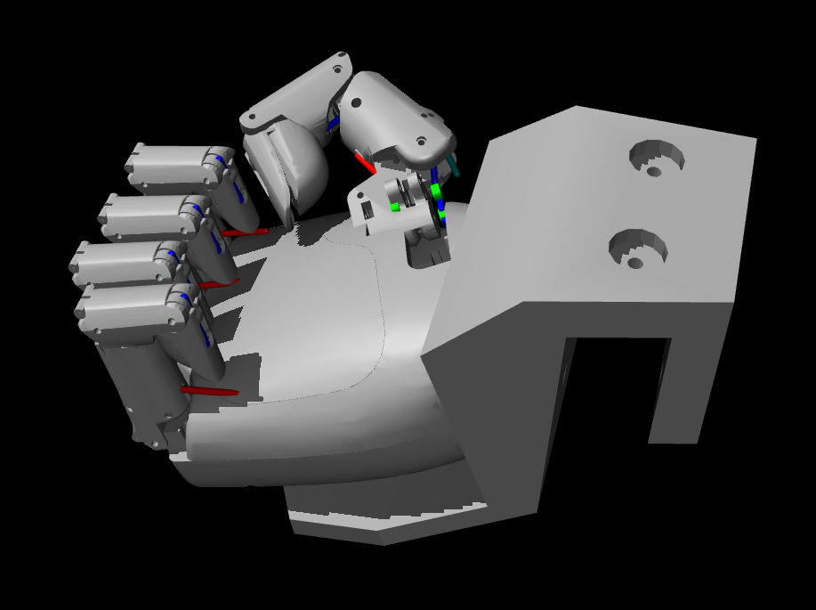
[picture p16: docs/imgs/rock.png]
Rock
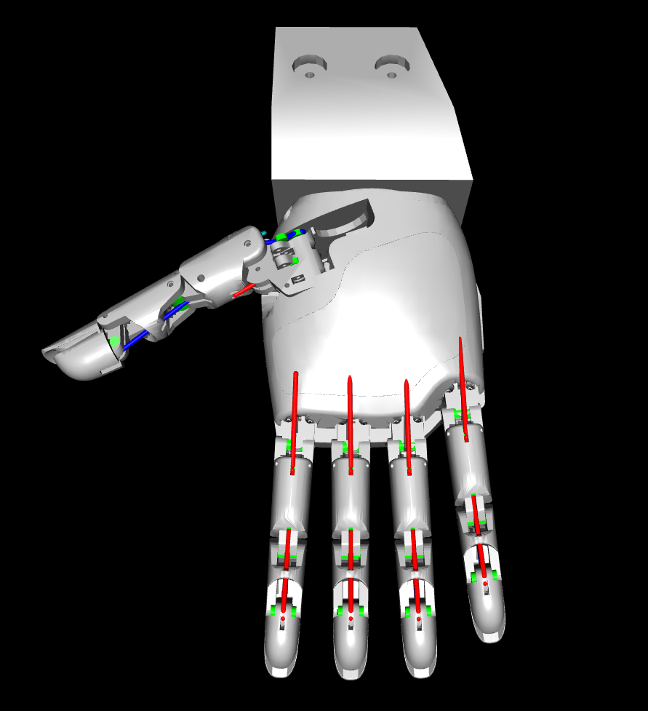
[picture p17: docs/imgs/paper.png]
Paper
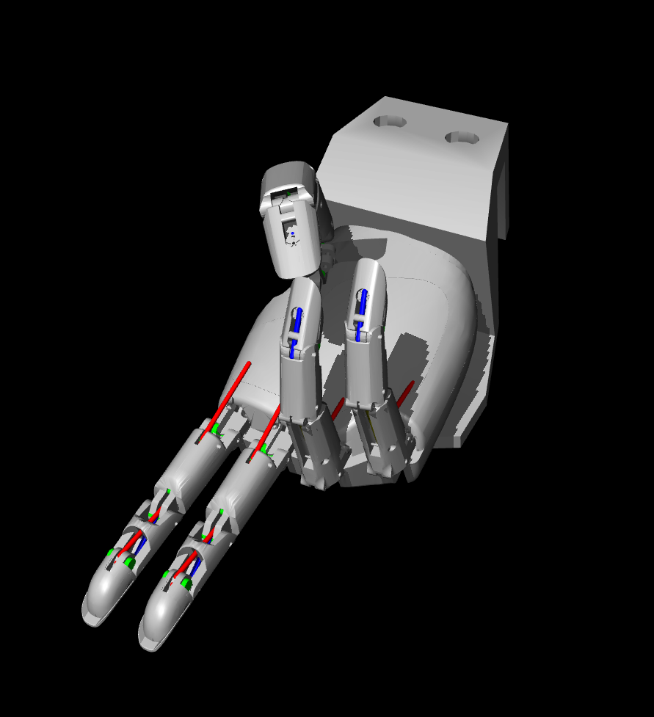
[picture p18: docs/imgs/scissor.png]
Scissor
|  |  |  |
|---|---|---|

---

## 1. TetherIA Aero Hand Model

### 1.1 Modeling

The simulation model is derived from URDF models, accurately representing the real mechanical structure. The simulation reproduces the cable actuation through three essential components:

#### 1.1.1 Tendon Drives
Spatial tendons drive the fingers and thumb, following the same routing paths as the real hand.

#### 1.1.2 Springs
Modeled as tendon elements, springs generate restoring forces for finger extension, mirroring the real mechanical springs.

#### 1.1.3 Pulleys
Cylindrical pulleys guide cables and springs to ensure accurate routing and consistent actuation behavior.

| Front view | Close-up of index |
|---|---|
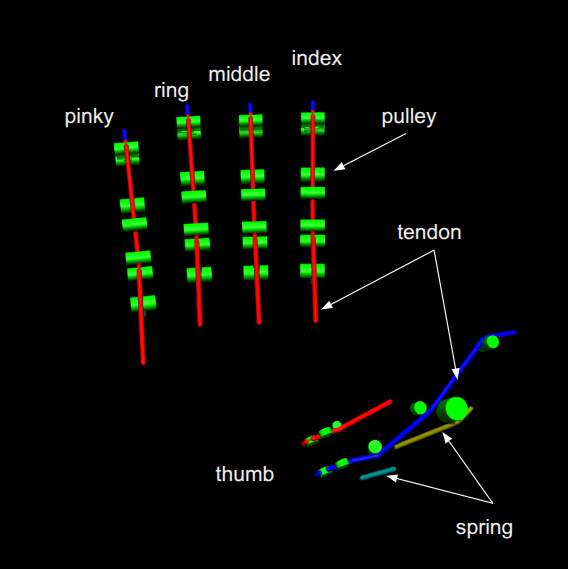
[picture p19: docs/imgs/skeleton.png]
skeleton
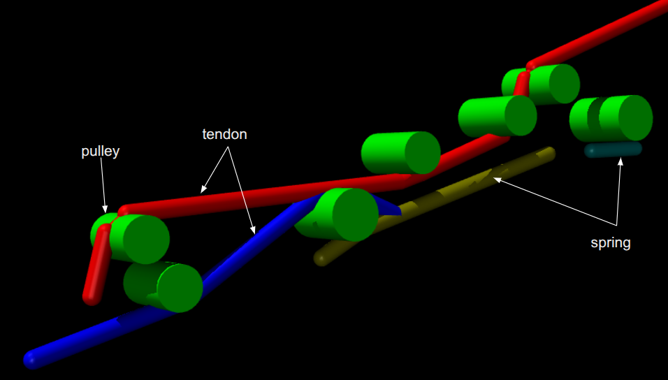
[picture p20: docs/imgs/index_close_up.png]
index
|  |  |

---

### 1.2 Parameters

#### 1.2.1 Mechanical Parameters
- **Joint limits, mass, and inertia:** directly taken from the URDF for physical fidelity.  
- **Pulley placement:** matches the real hand’s geometry, ensuring correct cable and spring routing.  
- **Validation:** the simulated tendon range (0.0459454 m) closely matches the real hand (0.04553 m) without manual adjustment.

#### 1.2.2 Tendon and Spring Specifications
- **Tendon properties:** identical to the real system.  
- **Spring properties:** match hardware specifications, except for the DIP spring—adjusted slightly for more realistic motion.

#### 1.2.3 Control Parameters
All remaining control parameters are fine-tuned to ensure consistent dynamics between simulation and hardware, including:
- Joint damping values  
- Actuator gains  
- Joint-specific damping coefficients. 

---

## 2. Training a Tendon-Space Policy

We introduce a **Z-axis rotation task** for the **TetherIA Aero Hand Open**, optimized using the following reward function:

reward = 1.0 × angular velocity - 1.0 × action rate + termination (-100.0)

The optimization variables include **tendon lengths** and the **thumb abduction joint**, both corresponding to the real actuation system. This design ensures that the same control and sensing channels can be directly applied in **sim-to-real deployment**.

To train the policy:

```bash
python learning/train_jax_ppo.py --env_name AeroCubeRotateZAxis
```

While training results vary slightly due to stochasticity, runs consistently **converge toward a positive total reward**. Below are example reward curves obtained using PPO:

**Overall Reward**
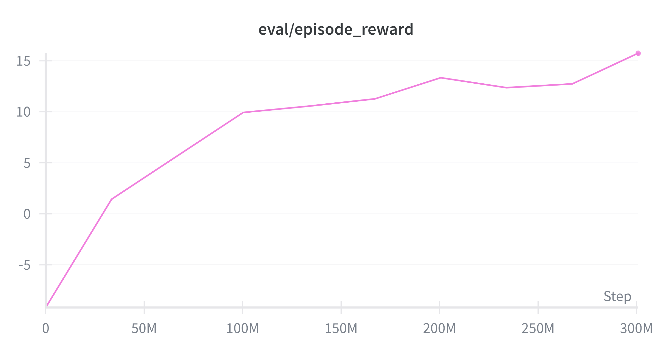
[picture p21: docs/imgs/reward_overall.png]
overall


**Angular Velocity Reward**
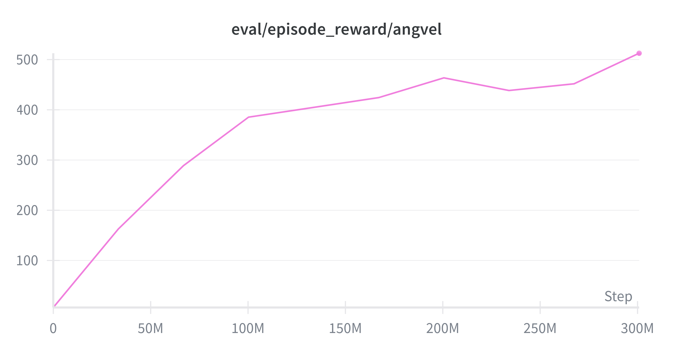
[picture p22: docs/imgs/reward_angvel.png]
reward_angvel


**Action-Rate Penalty**
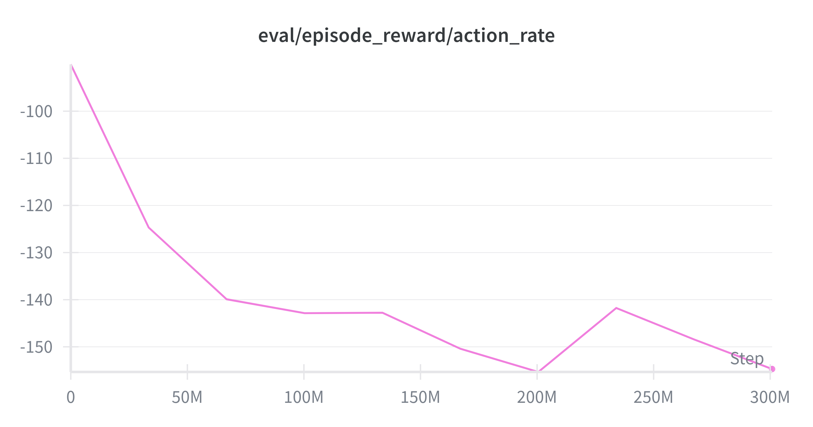
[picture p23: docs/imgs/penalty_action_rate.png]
penalty_action_rate


**Termination Penalty**
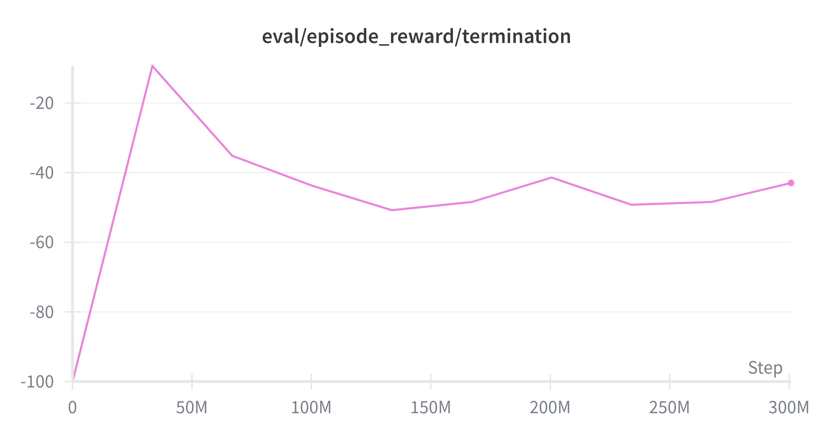
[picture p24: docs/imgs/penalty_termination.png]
penalty_termination


---

## 3. Running a Pretrained Policy

This example builds upon **[MuJoCo Playground](https://github.com/google-deepmind/mujoco_playground)** as an educational platform. We are actively working to merge **[our implementation](https://github.com/TetherIA/mujoco_playground_pr)** into the official repository.

To test a trained policy:
```bash
python learning/train_jax_ppo.py
--env_name AeroCubeRotateZAxis
--play_only
--load_checkpoint_path path/to/checkpoints
```

This will:
- Load the trained PPO policy  
- Run rollouts in simulation  
- Visualize the manipulation behavior

| Seed 0 | Seed 1 | Seed 14 |
|---|---|---|
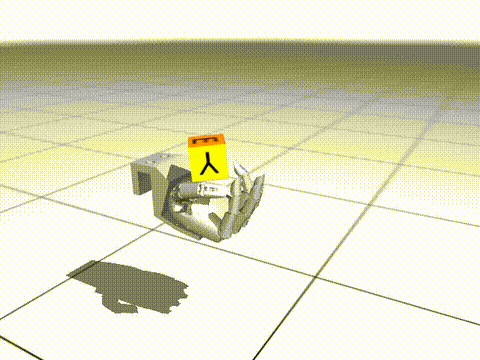
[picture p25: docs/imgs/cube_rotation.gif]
seed0
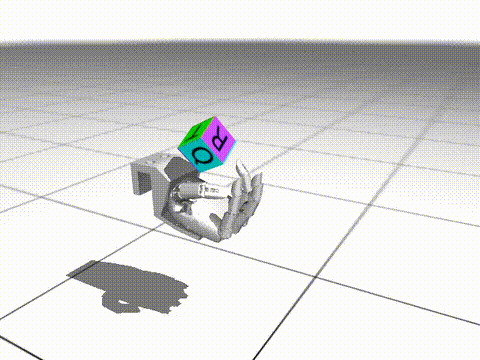
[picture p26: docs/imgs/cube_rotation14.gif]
seed14
|  | seed1 |  |

**Sim-to-Real Deployment on the TetherIA Aero Hand Open**

Z-Axis Rotation Demo

*Note: The finger markers are for visualization only and are **not** used for control.*

---

## 🧩 Acknowledgements

Dependency:  
- [**MuJoCo Playground**](https://github.com/google-deepmind/mujoco_playground). 

<div align="center">

Made with ❤️ by **TetherIA Robotics**

</div>

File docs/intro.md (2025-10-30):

# Aero Hand Open

<div style={{ display: "flex", justifyContent: "center", gap: "1rem", marginTop: "1rem" }}>
  <div style={{ textAlign: "center" }}>
    Open Palm Pose
    <p><em>Aero Hand Open</em></p>
  </div>
</div>

**Aero Hand Open** is a tendon-driven, under-actuated dexterous robotic hand built for research in manipulation, reinforcement learning, and embodied AI.  
It is designed for reproducibility, transparency, and ease of integration across hardware, firmware, and software layers.

---

## Hardware Overview

The hand adopts a **tendon-driven actuation architecture**, where each motor drives multiple joints through cable routing.  
This approach achieves high dexterity with fewer actuators, resulting in a lightweight and compliant design.

**Key characteristics:**
- 16 Degrees of Freedom (7 active, 9 passive)
- 3 active DoFs for the thumb, enabling real dexterity
- One-motor-per-finger tendon actuation
- Passive 1:1 coupling between DIP and PIP joints
- Adaptive coupling at MCP joint for compliant contact behavior
- Compact servo actuator modules with integrated encoders
- Modular 3D-printable mechanical components
- 6 V DC power input and USB communication
- Fully open-source CAD and PCB design

All mechanical and electrical design files are available in the [`hardware`](https://github.com/TetherIA/aero-hand-open/tree/main/hardware) folder.

---

## Firmware and Control

The onboard controller runs custom firmware supporting:
- Position, velocity, and torque control modes
- High-frequency communication over USB
- Real-time command streaming via Python SDK
- Built-in calibration and diagnostics utilities

Firmware source code is hosted in the [`firmware`](https://github.com/TetherIA/aero-hand-open/tree/main/firmware) folder.

---

## SDK and ROS 2 Integration

Developers can interface with the hand through:
- A **Python SDK** for joint, tendon, and sensor interfaces
- **ROS 2 packages** exposing communication, teleoperation, and and RL policy deployment, etc.
- Example nodes for control, data collection, and policy playback

Software API is maintained in the [`sdk`](https://github.com/TetherIA/aero-hand-open/tree/main/sdk) folder.

ROS2 packages is maintained in the [`ros2`](https://github.com/TetherIA/aero-hand-open/tree/main/ros2) folder.

---

## Simulation and Learning

Aero Hand Open is fully supported in **MuJoCo** with upcoming Issac Sim support, with tendon-level actuation and observation.  
It integrates with popular RL and imitation learning frameworks, including **MuJoCo Playground** and **LeRobot** (coming soon), enabling a consistent sim-to-real workflow.

Use simulation to train control policies, benchmark algorithms, and prototype manipulation tasks before deployment on real hardware.

---

## Repository Structure

| Component | Repository | Description |
|---|---|---|
| Monorepo | [`aero-hand-open`](https://github.com/TetherIA/aero-hand-open) | Consolidated repository for community contributions |
| Hardware | [`hardware folder`](https://github.com/TetherIA/aero-hand-open/tree/main/hardware) | CAD models, assembly, and PCB design|
| Firmware | [`firmware folder`](https://github.com/TetherIA/aero-hand-open/tree/main/firmware) | Embedded control software |
| SDK / GUI | [`sdk folder`](https://github.com/TetherIA/aero-hand-open/tree/main/sdk) | Python SDK and GUI |
| ROS2 | [`ros2 folder`](https://github.com/TetherIA/aero-hand-open/tree/main/ros2) | ROS2 packages for URDF, TeleOp, RL policy deployment, etc. |
| Documentation | [`docs folder`](https://github.com/TetherIA/aero-hand-open/tree/main/docs) | Documentation source |

---

## Getting Started

- [Build and assemble the hand →](./assembly.md)  
- [Set up hardware→](./hardware_setup.md) 
- [Flash and verify firmware →](./getting_started.md) 
- [Getting Started with GUI or SDK →](./sdk.md)   
- [Run simulation in MuJoCo →](./hand_sim.md)
- [Understand and modify firmware →](./firmware.md)

---

## License

All components of Aero Hand Open are released under permissive open-source licenses.  
Please refer to the [LICENSE FILE](https://github.com/TetherIA/aero-hand-open/blob/main/LICENSE.md) for license details.

<div align="center">

Made with ❤️ by **TetherIA Robotics**

</div>

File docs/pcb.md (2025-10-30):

# PCB Overview

The Aero Hand consists of two custom PCB boards: **Board A** and **Board B**. All design files - including Gerber files, KiCad project files, BOM, and CPL - are available in our [GitHub Repository Link](<https://github.com/TetherIA/aero-hand-open/tree/main/hardware>).

---

## Board A
- Features **8 Molex connectors** for connecting all servos in the hand.
- Includes a **JST connector P3.96mm** for outer wiring and fitting inside the hand enclosure.
- Designed for compact integration and reliable servo connectivity.
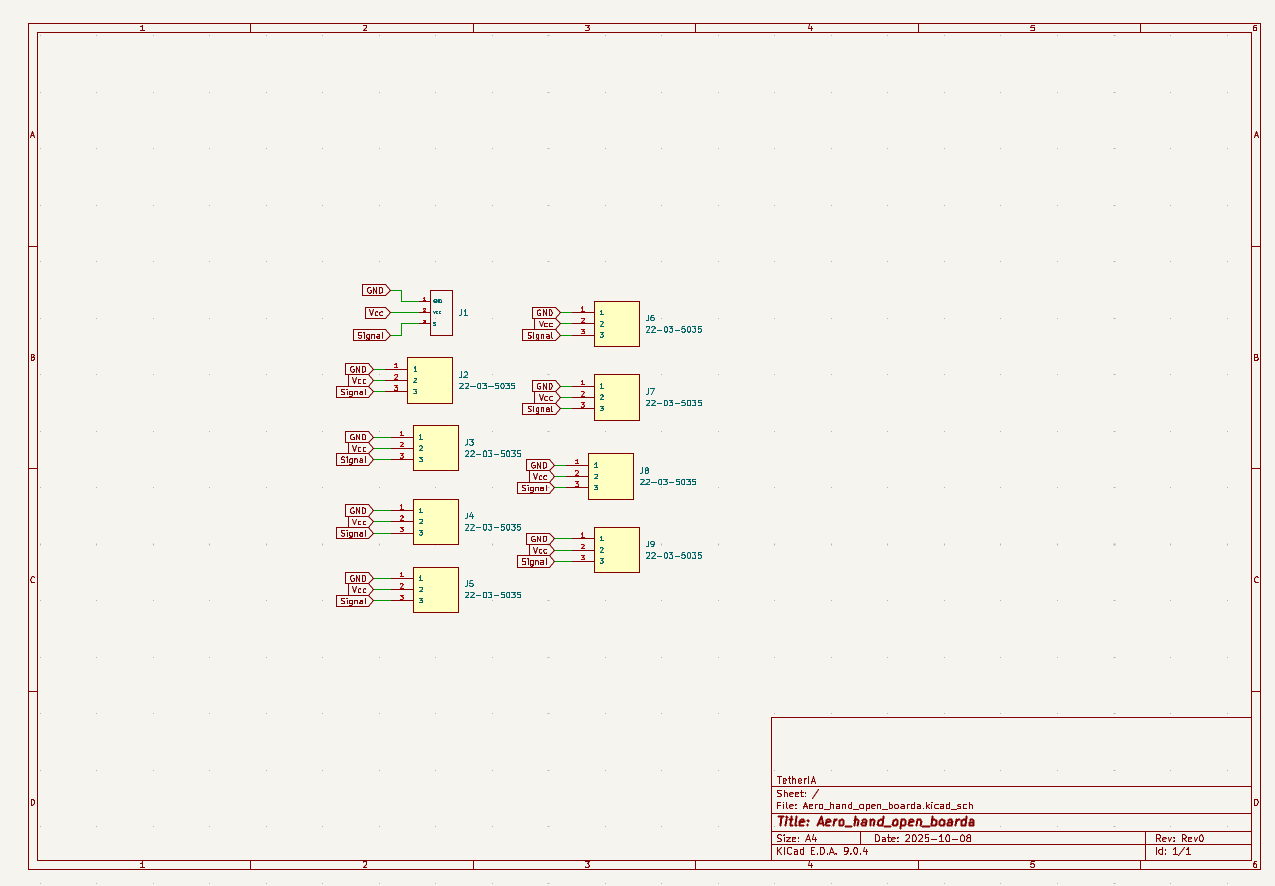
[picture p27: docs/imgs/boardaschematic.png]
Board A schematic showing 8 Molex connectors and JST connector P3.96mm

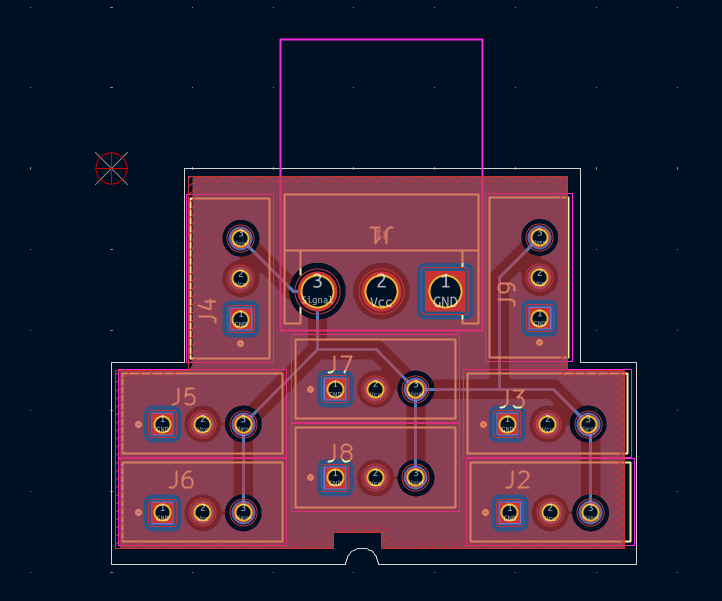
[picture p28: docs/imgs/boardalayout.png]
Board A PCB layout view

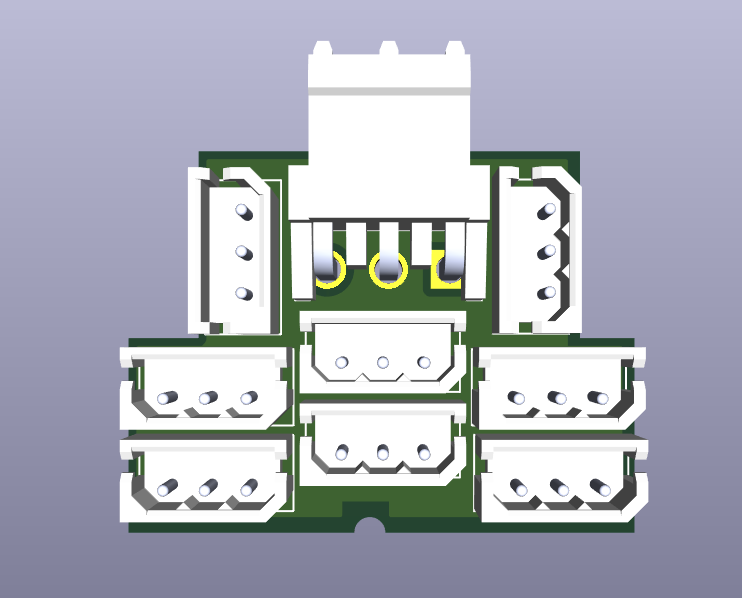
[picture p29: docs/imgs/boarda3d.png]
Board A 3D rendered view


## Board B
- Includes a **JST connector** and **one Molex connector** for testing individual servos and debugging.
- Features a **terminal block** to connect a regulated 6V, 10A power supply for the servos.
- Hosts the **ESP32-S3** microcontroller with a **USB-C port** for:
	- Powering the ESP32-S3
	- Communication between PC and ESP32-S3
	- Interfacing with the hand
- Board B is essential for diagnostics and safe power delivery.
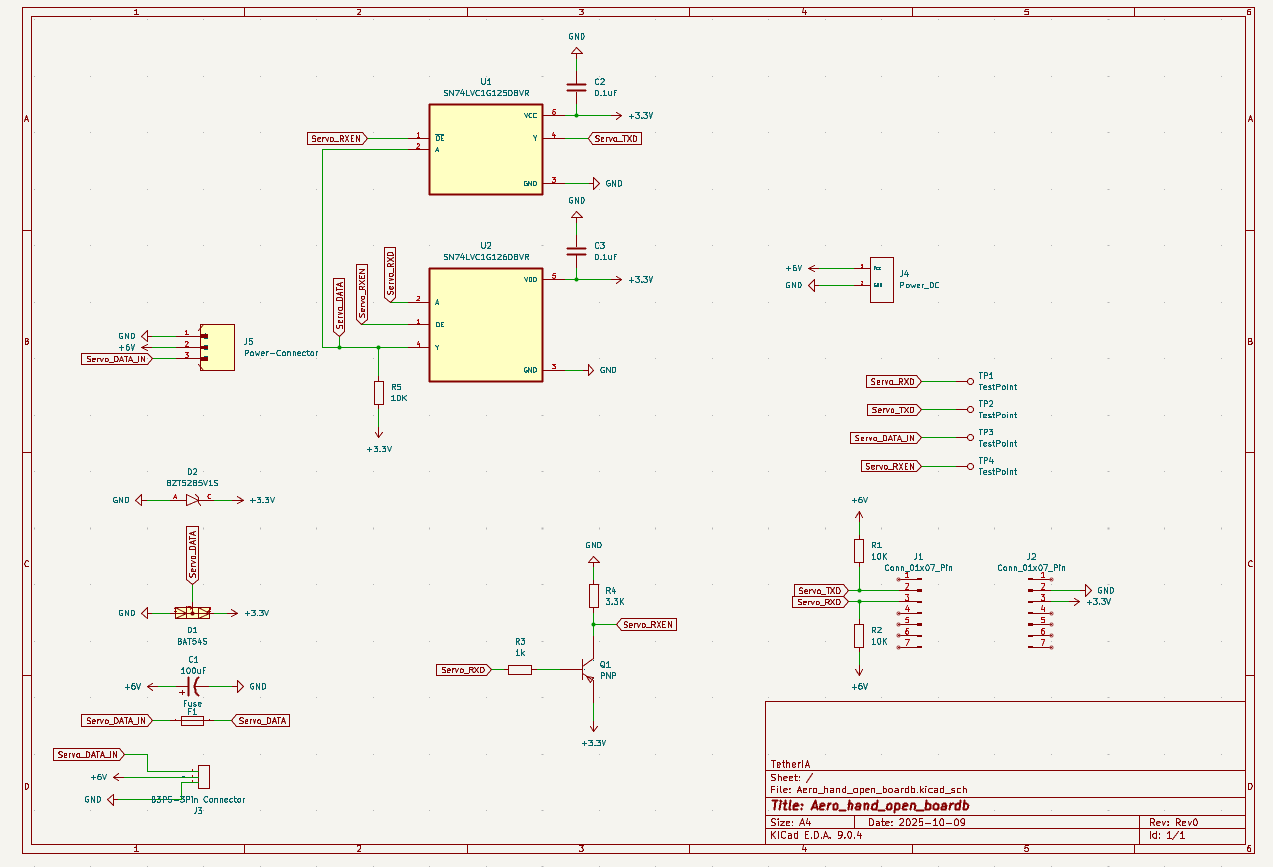
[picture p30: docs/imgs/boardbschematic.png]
PCB Schematic Board B

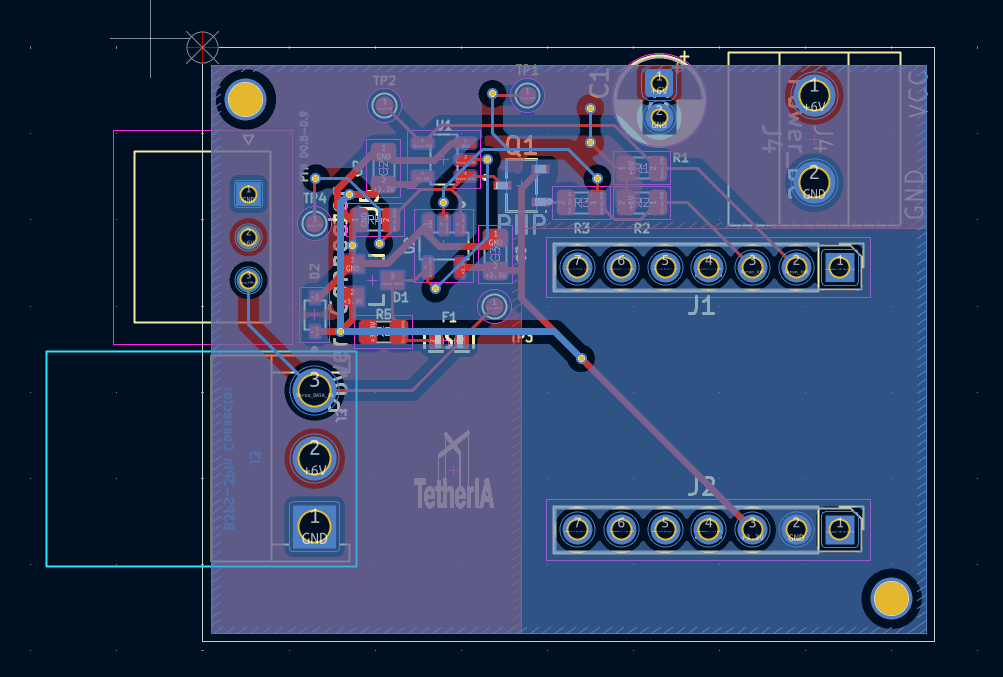
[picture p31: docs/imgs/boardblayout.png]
PCB layout Board B

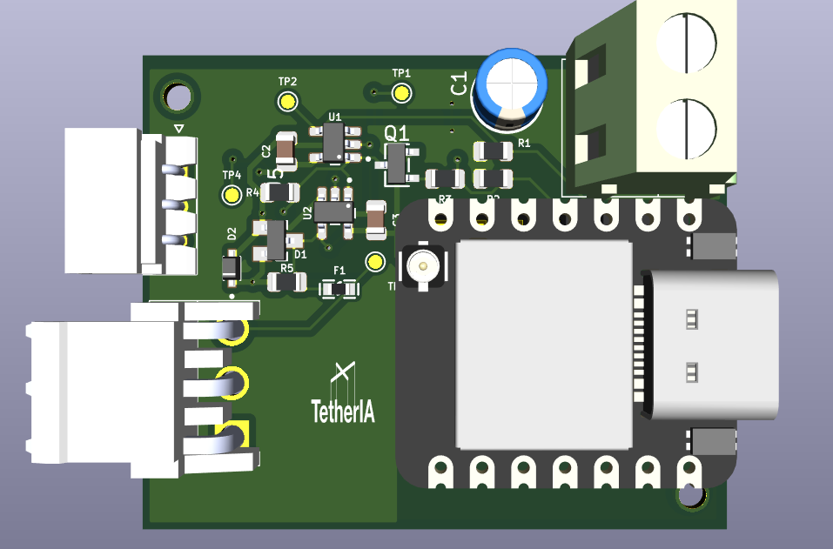
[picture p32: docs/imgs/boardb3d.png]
Board B 3D rendered view


---

For more details on communication and control, refer to our [SDK Documentation](https://github.com/TetherIA/aero-open-sdk).

<div align="center">

Made with ❤️ by **TetherIA Robotics**

</div>

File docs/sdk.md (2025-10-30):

# Software

After [assembling your hand](/docs/mechanical.md) and setting up the actuators (more on that in the [GUI section](#️-gui)), you can control your Aero hand using our Python SDK. SDK manages serial communication with the hardware using TetherIA’s custom [communication protocol](firmware.md).

---

## ⚙️ Installation

The SDK is currently tested for Python 3.10 and supports Linux and Windows.

### 📦 Install via pip

```bash
pip install aero-hand-sdk
```

### 🧩 Install from source (editable mode)

1. Clone the repository:
   ```bash
   git clone https://github.com/TetherIA/aero-open-sdk.git
   ```

2. Navigate to the cloned repository:
   ```bash
   cd aero-open-sdk
   ```

3. Install the package in editable mode:
   ```bash
   pip3 install -e .
   ```

---

## 🖥️ GUI
When setting up your hand for the first time, the **setup GUI** helps you configure actuator IDs and test the connections.
Make sure you've installed the SDK before running the below command [(see Installation)](#️-installation)

Run the GUI with:

```bash
aero-hand-gui
```

You’ll see an interactive configuration interface similar to below:

GUI Screen

<!-- @Harsh-Panara Add more details on the GUI usage and first time setup here.\ -->

### 🪛 First-Time Setup

For a complete First-Time guide, see [Getting Started](./getting_started.md).
1. Assigning Actuator IDs
2. Testing Actuator Connections
3. Performing Initial Homing and Calibration

## 🧰 SDK Overview

The SDK exposes a high-level Python API for commanding, monitoring, and debugging the hand.

### 🔌 Initialization

You can intialize the hand using the `AeroHand` class:

```python
from aero_open_sdk.aero_hand import AeroHand

aero_hand = AeroHand(port="/dev/ttyACM0")
```
This will open the `serial` port for communicating with the hand. 

:::note
By default, **Linux** assigns the first connected device to `/dev/ttyACM0`, while **Windows** typically uses `COM1` or `COM2`.  
However, this is **not guaranteed**, the exact port may vary depending on your system and connected devices.  
Always verify the correct port before initializing the hand.  
For detailed steps on identifying and configuring serial ports, refer to our [GitHub repository](https://github.com/TetherIA/aero-open-sdk/blob/0253a652b03a7973af04be3f18baab1a736d240e/README.md).
:::

### ✋ Joint Representation

Our Robot Hand has 16 Joints - 4 For the Thumb and 3 for each of the four finger.

#### 🧾 Joint Naming and Indexing Convention

We use the following joint naming and indexing convention to refer to each joint in the software. The naming follows standard anatomical terminology, and the indexing flows:
 - From thumb to pinky finger
 - and from base to tip, within each finger.

| Finger | Joint Name | Index |
|---|---|---|
| Thumb | thumb_cmc_abd | 0 |
| Thumb | thumb_cmc_flex | 1 |
| Thumb | thumb_mcp | 2 |
| Thumb | thumb_ip | 3 |
| Index | index_mcp | 4 |
| Index | index_pip | 5 |
| Index | index_dip | 6 |
| Middle  | middle_mcp | 7 |
| Middle  | middle_pip | 8 |
| Middle  | middle_dip | 9 |
| Ring | ring_mcp | 10 |
| Ring | ring_pip | 11 |
| Ring | ring_dip | 12 |
| Pinky | pinky_mcp | 13 |
| Pinky | pinky_pip | 14 |
| Pinky | pinky_dip | 15 |

To get the joint names programmatically:

```python
print(aero_hand.joint_names)
```
Expected output:
```
['thumb_cmc_abd', 'thumb_cmc_flex', 'thumb_mcp', 'thumb_ip', 'index_mcp', 'index_pip', 'index_dip', 'middle_mcp', 'middle_pip', 'middle_dip', 'ring_mcp', 'ring_pip', 'ring_dip', 'pinky_mcp', 'pinky_pip', 'pinky_dip']
```

#### 📏 Joint Limits

Each joint has a specific range of motion defined by its lower and upper limits.

By convention:
- The minimum angle (0 °) corresponds to a fully extended joint, which translates to an open palm pose.
- The maximum angle corresponds to a fully flexed joint, which translates to a closed fist pose.

<div style={{ display: "flex", justifyContent: "center", gap: "1rem", marginTop: "1rem" }}>
  <div style={{ textAlign: "center" }}>
    Open Palm Pose
    <p><em>Open Palm Pose(Min Joint Angles)</em></p>
  </div>
  <div style={{ textAlign: "center" }}>
    Closed Fist Pose
    <p><em>Closed Fist Pose(Max Joint Angles)</em></p>
  </div>
</div>

These conventions are consistent across all joints for clarity and ease of control.

Each joint's limits in degrees are as per below Table:

| Joint Name | Min (°) | Max (°) |
|---|---|---|
| thumb_cmc_abd | 0 | 100 |
| thumb_cmc_flex | 0 | 55 |
| thumb_mcp | 0 | 90 |
| thumb_ip | 0 | 90 |
| index_mcp | 0 | 90 |
| index_pip | 0 | 90 |
| index_dip | 0 | 90 |
| middle_mcp | 0 | 90 |
| middle_pip | 0 | 90 |
| middle_dip | 0 | 90 |
| ring_mcp | 0 | 90 |
| ring_pip | 0 | 90 |
| ring_dip | 0 | 90 |
| pinky_mcp | 0 | 90 |
| pinky_pip | 0 | 90 |
| pinky_dip | 0 | 90 |

To get the joint limits programmatically:

```python
print(aero_hand.joint_lower_limits)
print(aero_hand.joint_upper_limits)
```

### 🎮 Controlling the Hand

To control the hand, api expose `set_joint_positions` method which takes in a list of 16 joint angles in degrees and moves the hand correspondingly.

:::note
`set_joint_positions` method can also take in a list of 7 joint angles(compact representation) in degrees as input. More on that in next section.
:::

```
target_positions = [30.0, 20.0, 45.0, 45.0, 90.0, 90.0, 90.0, 90.0, 90.0, 90.0, 90.0, 90.0, 90.0, 90.0, 90.0, 90.0]
aero_hand.set_joint_positions(target_positions)
```

### 🔗 Joints to Actuations Mapping
The hand uses 7 actuators to drive 16 joints through a tendon-driven mechanism, resulting in an under-actuated system where multiple joints are coupled.
While we can only control 7 actuators in the hand, we found it useful to think in terms of 16 independent joint angles as many teleoprations systems are designed to work with joints angles. Also, actuators in the thumb are coupled in the sense that movement of one joint affects multiple actuators to maintain the other joint positions.

For example:
- To move only the thumb_cmc_flex joint, we actuate the corresponding actuator. However, this also pulls the tendons that control the thumb_mcp and thumb_ip joints, causing them to move as well.  
- Similar coupling exists for the thumb_cmc_abd joint as well, which affects all three actuators in the thumb.

We handle these coupling effects through the joints-to-actuations mapping. Curious users can explore the implementation in the [`joints_to_actuations.py`](https://github.com/TetherIA/aero-open-sdk/blob/9ed354aa429a97728cd94b616776ebd62bf5eff9/src/aero_open_sdk/joints_to_actuations.py) file for details.

Typically, you won’t need to worry about these coupling effects, as the `set_joint_positions()` method automatically applies this mapping internally to convert joint angles into actuator commands.

#### Compact Joint Representation
While using the 16 joint angles to control the hand is descriptive, as the hand only has 7 actuators it can become cumbersome and time consuming to provide all the 16 joint values to the `set_joint_positions` method all the time.
This is especially true for users who want to define some hand poses manually for making the robot perform a sequence of actions rather then using a teleoperation system.
To handle this, `set_joint_positions` method can also take in a compact representation of 7 joint angles in degrees as input.
The compact representation consists of the following 7 entries, representing a grouped motion of joints that are controlled by a single actuator:

| Index | Joint Controlled | Description |
|---|---|---|
| 0 | thumb_cmc_abd | single actuator for thumb_cmc_abd |
| 1 | thumb_cmc_flex | single actuator for thumb_cmc_flex |
| 2 | thumb_mcp & thumb_ip | both joints are controlled by one actuator |
| 3 | index_mcp, index_pip & index_dip | All three joints of the index finger are controlled by a single actuator. |
| 4 | middle_mcp, middle_pip & middle_dip | All three joints of the middle finger are controlled by a single actuator. |
| 5 | ring_mcp, ring_pip & ring_dip | All three joints of the ring finger are controlled by a single actuator. |
| 6 | pinky_mcp, pinky_pip & pinky_dip | All three joints of the pinky finger are controlled by a single actuator. |

`set_joint_positions` method will convert this compact representation to the full 16 joint angles representation internally by copying the values to the joints that are controlled by the same actuator.

Below table shows the internal mapping from 7 to 16 joint angles if the user provides 7 joint angles as below:

| Input (7 joints) | 45 | 30 | 60 | 30 | 45 | 60 | 90 |
|---|---|---|---|---|---|---|---|
| Output (16 joints) | 45 | 30 | 60 60 | 30 30 30 | 45 45 45 | 60 60 60 | 90 90 90 |

The above representation might be more intuitive to some users as the user can think in terms of controlling the fingers as a whole rather than individual joints. 

The above example can be intuitively read as:
- move thumb cmc abduction to 45 degrees
- move thumb cmc flexion to 30 degrees
- move thumb mcp and thumb ip to 60 degrees
- move all joints of index finger to 30 degrees
- move all joints of middle finger to 45 degrees
- move all joints of ring finger to 60 degrees
- move all joints of pinky finger to 90 degrees

Programmatically this can be done as below:

```python
compact_target_positions = [45.0, 30.0, 60.0, 30.0, 45.0, 60.0, 90.0]
aero_hand.set_joint_positions(compact_target_positions)
```

:::note
1. The joint limits for all the joints will still apply and have similar meaning to the complete 16 joint angle representation.
2. Sending the above command doesn't guarantee that the hand will move each joint to the angles specified in the table above, as the hand is under-actuated and the actual position will depend on the external forces acting on the hand.
:::

### 🔧 Actuation Position Control (Advanced)

While we recommend using the `set_joint_positions` method to control the hand, we also provide the `set_actuations` method for advanced users who need actuator-level control.  

:::note
**Important:** The thumb's CMC abduction, CMC flexion, and MCP-IP flexion are highly coupled by mechanical design. Always keep this coupling in mind when directly controlling the actuations. For example, if you change the `thumb_cmc_abd_act` value alone, you will observe that all thumb joints (CMC abduction, CMC flexion, MCP, and IP joints) will move due to the coupling mechanism.
:::

We use the below Actuations indexing and Naming conventions to refer to the actuators:
- 0 - thumb_cmc_abd_act
- 1 - thumb_cmc_flex_act
- 2 - thumb_tendon_act
- 3 - index_tendon_act
- 4 - middle_tendon_act
- 5 - ring_tendon_act
- 6 - pinky_tendon_act

This can also be accessed in the code by calling the `actuation_names` property of the AeroHand class.

```python
print(aero_hand.actuation_names)
```

Expected output:
```python
['thumb_cmc_abd_act', 'thumb_cmc_flex_act', 'thumb_tendon_act', 'index_tendon_act', 'middle_tendon_act', 'ring_tendon_act', 'pinky_tendon_act']
```

Similar to joints, each actuator has a specific range of motion defined by its lower and upper limits. Actuations represents the degree of movement of the actuator.

By convention we set the zero actuations to correspond to the open palm pose(zero joint angles) and full actuation to correspond to closed fist pose(maximum joint angles). With this convention and our hand's mechanical design we get the actuation limits as below:

| Actuator Name | Min Actuation (degrees) | Max Actuation (degrees) |
|---|:---:|:---:|
| thumb_cmc_abd_act | 0 | 100 |
| thumb_cmc_flex_act  | 0 | 131.89 |
| thumb_tendon_act | -27.78 | 274.92 |
| index_tendon_act | 0 | 288.16 |
| middle_tendon_act | 0 | 288.16 |
| ring_tendon_act | 0 | 288.16 |
| pinky_tendon_act | 0 | 288.16 |

:::note
Notice that the thumb_tendon_act has a negative lower limit. This is due to the fact that the thumb_tendon is not at it's lower extreme when the hand is in open palm pose(zero joint angles). This is a result of the mechanical design of the hand and the tendon routing. For the curious readers, the lowest actuation of thumb tendon happens when the thumb cmc flex joint is at it's upper limit(55 degrees) and thumb cmc abduction joint is at it's lower limit(0 degrees). This could be calculated using the joints to actuation mapping. You can investigate the `joints_to_actuations.py` file to understand this in detail.
:::

Actuation limits can be accessed programmatically as below:
```python
print(aero_hand.actuation_lower_limits)
print(aero_hand.actuation_upper_limits)
```

To control the hand at the actuator level, you can use the `set_actuations` method which takes in a list of 7 actuation values in degrees.

```python
target_actuations = [50.0, 30.0, 100.0, 150.0, 150.0, 150.0, 150.0]
aero_hand.set_actuations(target_actuations)
```

### Actuation Torque Control
You can directly send torque control command to the seven motors. The torque control only works for the hand closing direction. The control API is `hand.ctrl_torque(torque_list)`.

See more examples in [torque control example](https://github.com/TetherIA/aero-open-sdk/blob/main/examples/torque_control.py) and [position torque switching](https://github.com/TetherIA/aero-open-sdk/blob/main/examples/position_torque_switching.py)

:::note
We recommend to use switching only when necessary as frequent switching may lead to unexpected behavior. If the hand is not responding as expected, please restart the program and try to do homing before switching modes.
:::

### 📡 Receiving Data from the Hand

The API also provides methods to read the current state of the actuators via various getter methods.

**Get Actuations**

To read the current actuator positions in degrees call the `get_actuations` method.

```python
current_actuations = aero_hand.get_actuations()
```

This will return a list of 7 actuations in degrees.

**Get Actuator Currents**

To read the current actuator currents in mA(milliAmpere) call the `get_actuator_currents` method.

```python
current_actuation_currents = aero_hand.get_actuator_currents()
```

This will return a list of 7 actuation currents in mA.

**Get Actuator Temperatures**

To read the current actuator temperatures in degree Celsius call the `get_actuator_temperatures` method.

```python
current_actuation_temperatures = aero_hand.get_actuator_temperatures()
```

This will return a list of 7 actuation temperatures in degree Celsius.

**Get Actuator Speeds**

To read the current actuator speeds in rpm call the `get_actuator_speeds` method.

```python
current_actuation_speeds = aero_hand.get_actuator_speeds()
``` 

This will return a list of 7 actuation speeds in rpm.

### 💡 Examples

To quickly get started with the SDK, check out the examples in our [GitHub repository](https://github.com/TetherIA/aero-open-sdk/tree/main/examples)

<div align="center">

Made with ❤️ by **TetherIA Robotics**

</div>

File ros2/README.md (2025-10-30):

<p align="center">
  Aero Hand Open by TetherIA
  <br/><br/>
</p>
 
<div align="center">




</div>

<h2 align="center">
  <p>Aero Hand ROS2 — ROS2 package for for TetherIA's Robotic Hand</p>
</h2>

<div align="center">
  Aero Hand Demo Aero Hand in action
  <p><strong>Aero Hand Open</strong> is a 7-DoF tendon-driven robotic hand for dexterous manipulation and research.</p>
</div>

---

## ⚙️ Installation

We currently have tested the ROS2 package on **Ubuntu 22.04** with **ROS2 Humble Hawksbill**.

### Prerequisites

Before installing this package, ensure you have:
- ROS2 Humble installed. Follow the official guide [here](https://docs.ros.org/en/humble/Installation/Ubuntu-Install-Debians.html).
- `colcon` build tool installed. You can install it via:
  ```bash
  sudo apt install python3-colcon-common-extensions
  ```
- The [Aero Hand SDK](https://github.com/TetherIA/aero-open-sdk.git) installed, follow the installation instructions in its README.

### Installation Steps

To install the `aero-open-ros2` package, follow these steps:

1. Clone the repository to your local machine:
   ```bash
   git clone https://github.com/TetherIA/aero-open-ros2.git
   ```

2. Navigate to the cloned repository directory:
   ```bash
   cd aero-open-ros2
   ```

3. Build the packages with colcon:
   ```bash
   colcon build
   ```

4. Source the workspace:
   ```bash
   source install/setup.bash
   ```

---

## 🚀 Next Steps

Take a look at the [Aero Hand Open README](src/aero_hand_open/README.md) next to get started with using the Aero Hand Open ROS2 package.

## 🧰 Troubleshooting

Coming soon — common setup and runtime issues will be documented here.

## 💬 Support

If you encounter issues or have feature requests:
- Open a [GitHub Issue](https://github.com/TetherIA/aero-open-ros2/issues)
- Contact us at **support@tetheria.ai**

---

## 🤝 Contribution

We welcome community contributions!

If you'd like to improve the SDK, fix bugs, or add new features:

1. Fork this repository.
2. Create a new branch for your changes.
    ```bash
    git checkout -b feature/your-feature-name
    ```

3. Commit your changes with clear messages.

4. Push your branch to your fork.

5. Open a Pull Request (PR) describing your updates.

---

## ⚖️ License

This project is licensed under the **Apache License 2.0**.

<div align="center">
If you find this project useful, please give it a star! ⭐

Built with ❤️ by TetherIA.ai
</div>

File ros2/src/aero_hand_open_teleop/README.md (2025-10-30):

# 🖐️ Aero Hand Open Teleoperation (Teleop) — ROS 2 Package

The **Aero Hand Open Teleoperation** package provides a ROS 2-based interface that enables real-time control of **TetherIA’s Aero Hand** using the **Manus gloves**.  

## 🧩 Overview

This package:
- Subscribes to **Manus glove data** published via `manus_ros2`.
- Retargets (maps) the human hand joint angles to Aero Hand’s robotic joint structure.
- Publishes joint-space commands to the **Aero Hand Open Node** (`aero_hand_open`).

## 🚀 Launch File

The package includes a launch file that brings up the complete teleoperation pipeline:
- Manus glove data stream (`manus_ros2`)
- Retargeting node (`aero_hand_open_teleop`)
- Aero Hand hardware node (`aero_hand_open`)

### Running the Teleop Stack
```bash
ros2 launch aero_hand_open_teleop aero_hand_teleop.launch.py
```

## 🧰 Dependencies

- **ROS 2 Humble** (or newer)
- **manus_ros2**
- **aero_open_sdk**
- **aero_hand_open**
- **aero_hand_open_msgs**

Ensure all packages are built in your workspace before launching.

## ⚖️ License

This project is licensed under the **Apache License 2.0**.

---

<div align="center">
If you find this project useful, please give it a star! ⭐  

Built with ❤️ by <a href="https://tetheria.ai">TetherIA.ai</a>
</div>

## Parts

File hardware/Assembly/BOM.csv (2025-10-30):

 | P/N | Name | Material | Qty per Hand | Volume (mm^3) | Total Cost per Hand | Link | Alternative | Notes
3D Printed | 1 | Finger Base | PLA | 4 | 975 | 0.024362813 | Bambu Lab |  | 3DP parts have been designed for PLA printed on a Bambu X1C with a 0.4mm nozzle. Tolerances may need to change if printing with different materials/nozzles/printers.
 | 2 | Finger MCP | PLA | 4 | 606 | 0.015142425
 | 3 | Finger Proximal | PLA | 4 | 5776 | 0.1443278
 | 4 | Finger Medial | PLA | 4 | 2644 | 0.06606695
 | 5 | Finger Distal | PLA | 4 | 1547 | 0.038655663
 | 6 | Cable Spool | PLA | 6 | 735 | 0.018365813
 | 7 | Thumb Abduction Upper Servo Disk | PLA | 1 | 786 | 0.019640175
 | 8 | Thumb Abduction Lower Servo Disk | PLA | 1 | 1366 | 0.034132925
 | 9 | Thumb Abduction Linkage Bar | PLA | 1 | 334 | 0.008345825
 | 10 | Thumb CMC Base | PLA | 1 | 5548 | 0.13863065
 | 11 | Thumb MCP | PLA | 1 | 11204 | 0.27995995
 | 12 | Thumb Proximal | PLA | 1 | 6926 | 0.173063425
 | 13 | Thumb Distal | PLA | 1 | 3912 | 0.0977511
 | 14 | Servo Frame | PLA | 1 | 15055 | 0.376186813
 | 15 | Palm Front Frame | PLA | 1 | 18734 | 0.468115825
 | 16 | Palm Rear Frame | PLA | 1 | 106254 | 2.655021825
 | 17 | Silicone molds Top | PLA | 1 | 39531 | 0.987780863
 | 18 | Silicone molds Bottom | PLA | 1 | 51643 | 1.290429463
Casting | 19 | Finger Distal Pad | 00-30 Silicone | 4 | 1322 | 0.02754653 | https://www.amazon.com/Ecoflex-00-30-Super-Platinum-Silicone/dp/B00CA5VY3U |  | We recomend using silicone pads to maximize compliance and grip however we also provide files for tpu to replace the foam. The hand functionality will be slightly lowered with the use of TPU.
 | 20 | Finger Proximal Pad | 00-31 Silicone | 4 | 1123 | 0.023399965
 | 21 | Thumb Distal Pad | 00-32 Silicone | 1 | 2998 | 0.062469363
 | 22 | Palm Frame Pad | 00-33 Silicone | 1 | 12180 | 0.253794808
 |  | Name | Material | Qty per Hand | Unit Cost | Total Cost Per Hand | Link | Alternative | Notes
Purchased Components | 23 | Finger Distal/Medial and Thumb Proximal/Distal Return Spring (PIP) | Music Wire | 5 | 5.27 | 26.35 | https://www.thespringstore.com/pe020-140-33500-mw-0840-mh-n-in.html
 | 24 | Finger Proximal/MCP Return Spring (MP) | Music Wire | 4 | 3.27 | 13.08 | https://www.centuryspring.com/shop/m-35cs
 | 25 | Thumb CMC/MCP Return Spring (CMC) | Music Wire | 1 | 4.93 | 4.93 | https://www.thespringstore.com/pe023-172-11218-mw-0470-mh-n-in.html
 | 26 | Finger Pull Cable | Kevlar/Vectran | 3 | 6.29 | 6.29 | https://www.amazon.com/9KM-DWLIFE-Strength-Retardant-Ridgeline/dp/B0B1WKH21R?s=sporting-goods | https://twinline-usa.com/collections/vectran-per-pound/products/braided-vectran-125-spools | The hand is designed to use this specific vectran however kevlar can be used
 | 27 | Pinky Pull Cable | Kevlar/Vectran | 1
 | 28 | Finger Coupling Cable | Kevlar/Vectran | 4
 | 29 | Thumb CMC Flex Cable | Kevlar/Vectran | 1
 | 30 | Thumb Pull Cable | Kevlar/Vectran | 1
 | 31 | Thumb Coupling Cable | Kevlar/Vectran | 1
 | 32 | 2x5x2.5 bearing | Steel | 23 | 0.5216 | 11.9968 | https://www.amazon.com/Yodaoke-MR52ZZ-2x5x2-5mm-Miniature-Bearings/dp/B08L7NTVK7 | https://us.misumi-ec.com/vona2/detail/221000531116/?list=PageCategory&Tab=catalog | Pins and bearings can vary depending on the supplier. The biggest issue will be fitting pins through the bearings. We reccomend buying undersized pins to ensure the pins maintain a slip fit with the bearings. We spec a cheap bearing from amazon that works, however if there are fitment issues we reccomend using the bearings from misumi
 | 33 | 1x10 Pin | Steel | 16 | 0.158 | 2.528 | https://www.mcmaster.com/91585A091/ | https://us.misumi-ec.com/vona2/detail/110300255260/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
 | 34 | 2x10 Pin | Steel | 2 | 0.159 | 0.318 | https://www.mcmaster.com/91585A221/ | https://us.misumi-ec.com/vona2/detail/110300255260/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
 | 35 | 2x14 Pin | Steel | 12 | 0.194 | 2.328 | https://www.mcmaster.com/91585A226/ | https://us.misumi-ec.com/vona2/detail/221000746912/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
 | 36 | 2x20 Pin | Steel | 2 | 1 | 2 | https://www.mcmaster.com/91585A240/ | https://us.misumi-ec.com/vona2/detail/110300255260/?HissuCode=MSCSS2-20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
 | 37 | UNDERSIZED 2x10 Pin | Steel | 17 | 0.156 | 2.652 | https://www.mcmaster.com/97049A104/ | https://us.misumi-ec.com/vona2/detail/110302390530/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
 | 38 | UNDERSIZED 2x20 Pin | Steel | 1 | 1.52 | 1.52 | https://us.misumi-ec.com/vona2/detail/110302390530/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 | https://us.misumi-ec.com/vona2/detail/110302390530/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
 | 39 | UNDERSIZED 2x30 Pin | Steel | 1 | 1.34 | 1.34 | https://us.misumi-ec.com/vona2/detail/110302390530/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 | https://us.misumi-ec.com/vona2/detail/110302390530/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
 | 40 | M2x6 Flanged Torx Self Tapping Screw | Steel | 25 | 0.403 | 10.075 | https://www.mcmaster.com/catalog/131/3434/96817A406
 | 41 | M2x10 Countersunk Torx Self Tapping Screw | Steel | 12 | 0.3 | 3.6 | https://www.mcmaster.com/95893A167/
 | 42 | M3x10 Rounded Torx Self Tapping Screw | Steel | 9 | 0.118 | 1.062 | https://www.mcmaster.com/96817A322/
 | 43 | M3x5.7 Heat set insert | Brass | 4 | 0.209 | 0.836 | https://www.mcmaster.com/94459A140/
 | 44 | Feetech HLS3606M Servo Motor | Comes with purchase of servo from Feetech | 7 | 29.83 | 208.81 | https://www.alibaba.com/product-detail/FEETECH-HLS3606M-6V-6Kg-cm-Torque_1601281149843.html
 | 45 | Servo Motor Mount Plate
 | 46 | Servo Motor Spline Screw M2.3x5
 | 47 | Servo Motor Plate Screw M2x4
 | 48 | Connection Board and Cable
 | 49 | TTLinker Mini UART Signal Conversion Board | PCB | 1 | 1.58 | 1.58 | https://www.alibaba.com/product-detail/TTLinker-Mini-UART-Signal-Conversion-Board_60370504430.html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
 | 50 | ESP32-S3 | PCB | 1 | 7.99 | 7.99 | https://www.seeedstudio.com/XIAO-ESP32S3-p-5627.html
 |  | Total |  |  |  | 316.488991
Optional |  | Molex Connector | - | 7 | 0.21 | 1.47 | https://www.digikey.com/en/products/detail/molex/0022035035/403302 |  | For optional soldered breadboard or you can use the Feetech junction boards that come with each servo to daisy chain the servos together and control them or you can buy/make the pcb design we are working on
 |  | Proto Board | - | 1 | 13.5 | 13.5 | https://www.sparkfun.com/sparkfun-snappable-protoboard.html

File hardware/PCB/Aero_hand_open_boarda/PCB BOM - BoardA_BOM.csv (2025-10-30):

Comment | Quantity | Designator | Footprint | JLCPCB Part | Link
MOLEX CONNECTOR | 8 | J2,J3,J4,J5,J6,J7,J8,J9 | MOLEX_22-03-5035 | C293315 | https://jlcpcb.com/partdetail/MOLEX-22035035/C293315
JST 3 PIN CONNECTOR | 1 | J1 | JST S3P-VH(LF)(SN) | C264986 | https://jlcpcb.com/partdetail/JST-S3P_VH_LF_SN/C264986

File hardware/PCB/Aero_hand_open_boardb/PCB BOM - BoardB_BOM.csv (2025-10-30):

Comment | Quantity | Designator | Footprint | JLCPCB Part | Link
100uF | 1 | C1 | CAP-TH-D5.0-P2.00-D0.8-FD | C47873 | https://jlcpcb.com/partdetail/48879-KM107M025D11RR0VH2FP0/C47873
0.1uF | 2 | C2,C3 | C_0805 | C520082 | https://jlcpcb.com/partdetail/YAGEO-CC0805JRX7R7BB104/C520082
BAT54S | 1 | D1 | BAT 4S KL4 | C8592 | https://jlcpcb.com/partdetail/9087-BAT54SKL4/C8592
BZT52B5V1S | 1 | D2 | DIO_BZT52B5V1S | C5261067 | https://jlcpcb.com/partdetail/HXYMOSFET-BZT52B5V1S/C5261067
BSMD0603-010-24V | 1 | F1 | F0603 | C883089 | https://jlcpcb.com/partdetail/BHFUSE-BSMD0603_01024V/C883089
MMBT2907A | 1 | Q1 | Transistor-SOT-23-3_L3.0-W1.7-P0.95-LS2.9-BR | C305431 | https://jlcpcb.com/partdetail/Foshan_Blue_RocketElec-MMBT2907A/C305431
10K | 3 | R1,R2,R5 | R_0805 | C702829 | https://jlcpcb.com/partdetail/HKR_Hong_Kong_Resistors-RCT0510KFLF/C702829
1K | 1 | R3 | R_0805 | C702831 | https://jlcpcb.com/partdetail/HKR_Hong_Kong_Resistors-RCT051KFLF/C702831
3.3K | 1 | R4 | R_0805 | C702834 | https://jlcpcb.com/partdetail/HKR_Hong_Kong_Resistors-RCT053K3FLF/C702834
SN74LVC1G126DBVR | 1 | U2 | SN74LVC1G126DBVR | C7834 | https://jlcpcb.com/partdetail/TexasInstruments-TISN74LVC1G126DBVR/C7834
SN74LVC1G125DBVR | 1 | U1 | SN74LVC1G125DBVR | C23654 | https://jlcpcb.com/partdetail/TexasInstruments-TISN74LVC1G125DBVR/C23654
Power_DC Connector Terminal BLOCK | 1 | J4 | KF127-5.08-2P | C474906 | https://jlcpcb.com/partdetail/Cixi_KefaElec-KF127_5_082P/C474906
JST 3 PIN Connector | 1 | J3 | JST S3P-VH(LF)(SN) | C264986 | https://jlcpcb.com/partdetail/JST-S3P_VH_LF_SN/C264986
Conn_01x07_Pin_RightESP | 1 | J2 | Conn_01x07_Pin_Right | C2935978 | https://jlcpcb.com/partdetail/DEALON-DM254R_11_0785/C2935978
Conn_01x07_Pin_LeftESP | 1 | J1 | Conn_01x07_Pin_Left | C2935978 | https://jlcpcb.com/partdetail/DEALON-DM254R_11_0785/C2935978
Right Angle 3P Molex | 1 | J5 | 22057035 MOLEX Right Angle Connector | C185225 | https://jlcpcb.com/partdetail/MOLEX-22057035/C185225

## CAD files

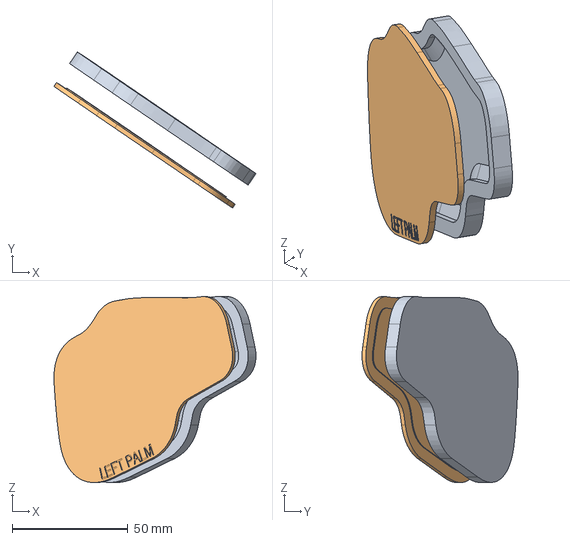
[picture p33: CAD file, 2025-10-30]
hardware/CAD/Molds/Palm_Silicone_Mold_L.stp
87.4 x 67.5 x 80.6 mm

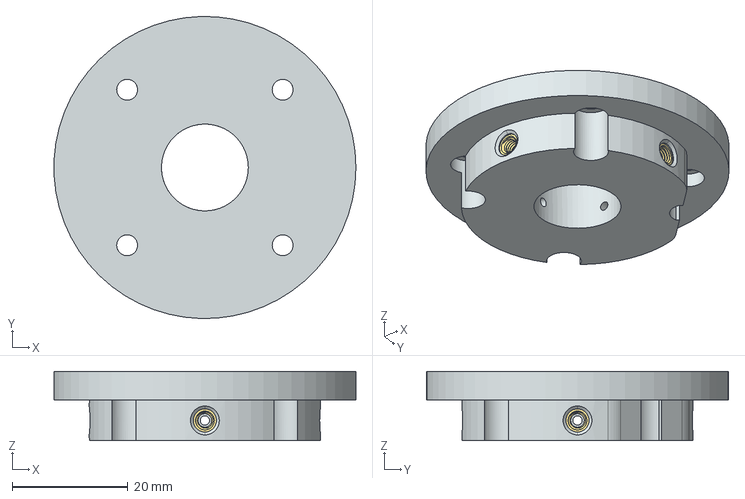
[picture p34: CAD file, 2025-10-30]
hardware/CAD/Robot_Arm_Mounts/PiPER_Arm_Mount.stp
52.2 x 52.2 x 12.0 mm

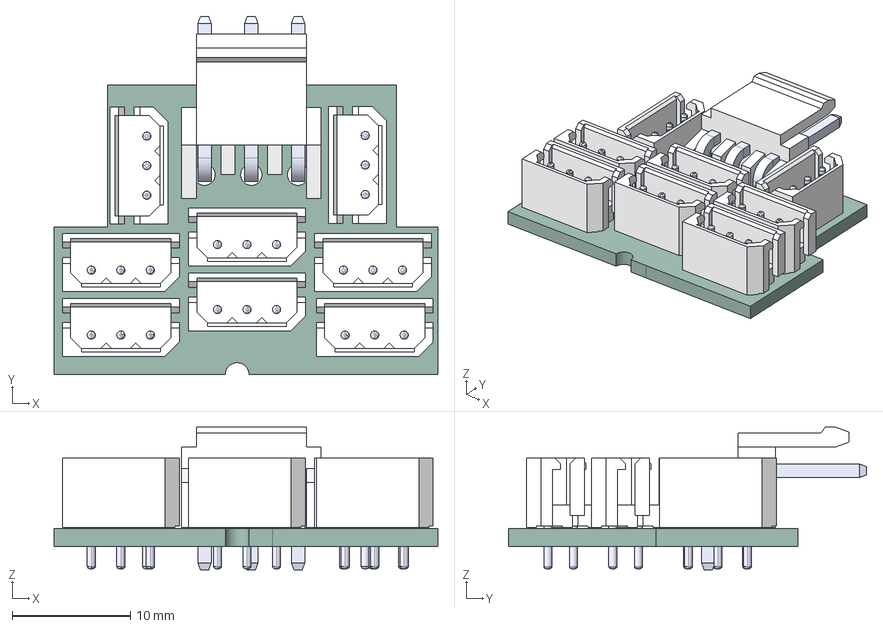
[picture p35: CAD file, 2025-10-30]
hardware/PCB/Aero_hand_open_boarda/Aero_hand_open_boarda.step
32.5 x 30.3 x 12.1 mm
S3P-VH-LF--SN---3DModel-STEP-56544
Aero_hand_open_boarda_PCB

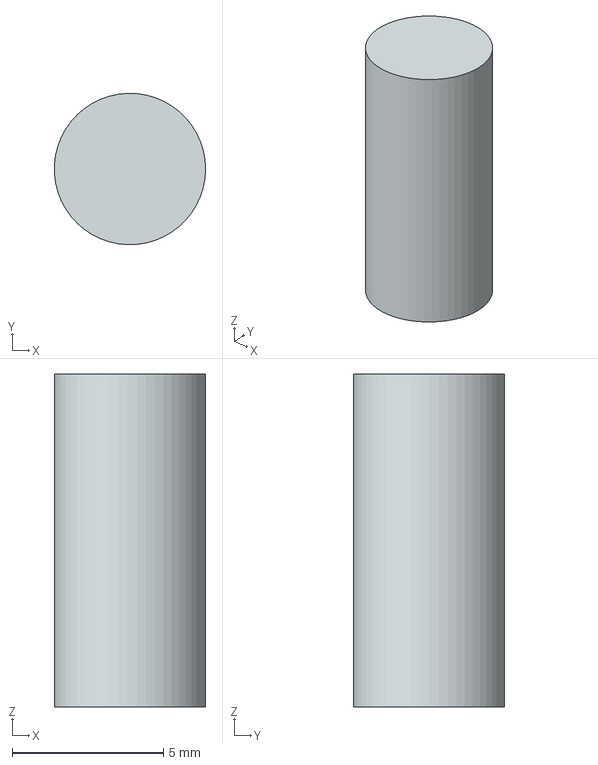
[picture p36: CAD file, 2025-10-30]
hardware/PCB/Components/100uF cap/100ufcap.stp
5.00 x 5.00 x 11.0 mm

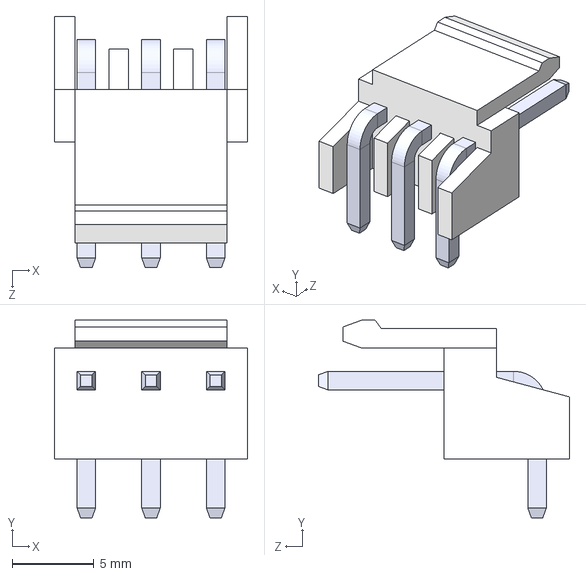
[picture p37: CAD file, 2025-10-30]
hardware/PCB/Components/3pin jst step file/S3P-VH-LF--SN---3DModel-STEP-56544.STEP
11.8 x 12.1 x 15.4 mm

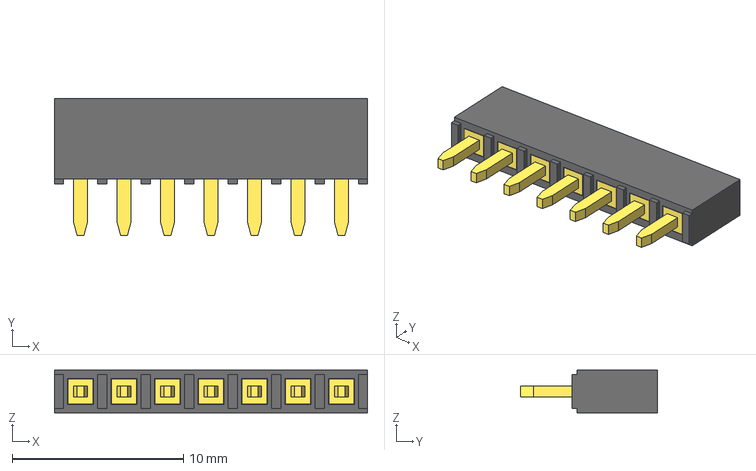
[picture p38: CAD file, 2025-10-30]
hardware/PCB/Components/7pinheadher 3dstep/7-Pin Header - Female - 2.54mm.step
18.3 x 8.00 x 2.50 mm

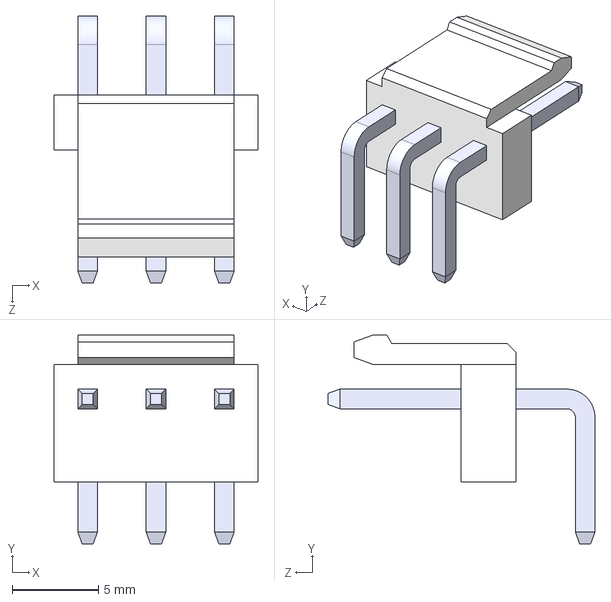
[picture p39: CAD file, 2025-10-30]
hardware/PCB/Components/B3PS-VH_LF_SN/B3PS-VH_LF__SN_.step
11.8 x 12.1 x 15.5 mm
BxPS-VH_3
pin^BxPS-VH ass x 3

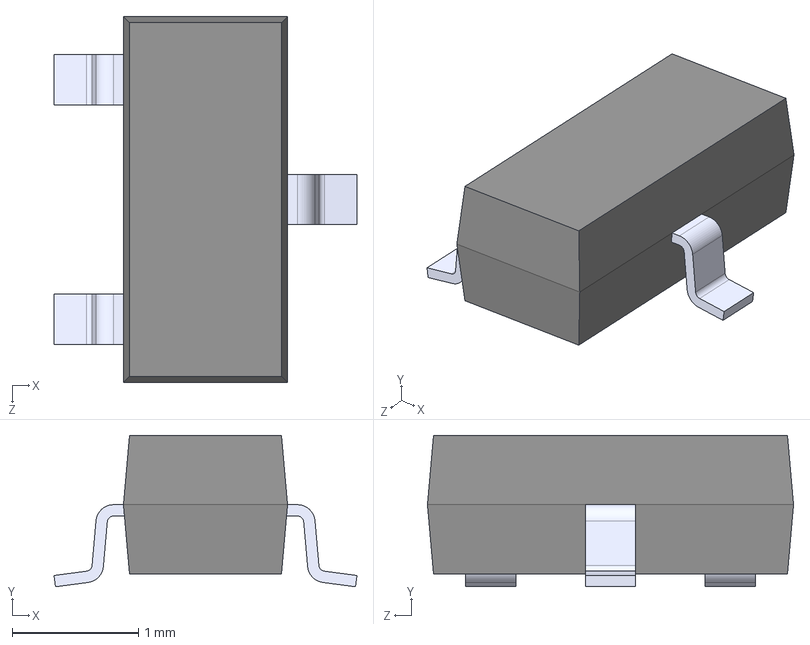
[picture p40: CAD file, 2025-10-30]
hardware/PCB/Components/BAT54S (1)/BAT54S.step
2.40 x 1.20 x 2.90 mm

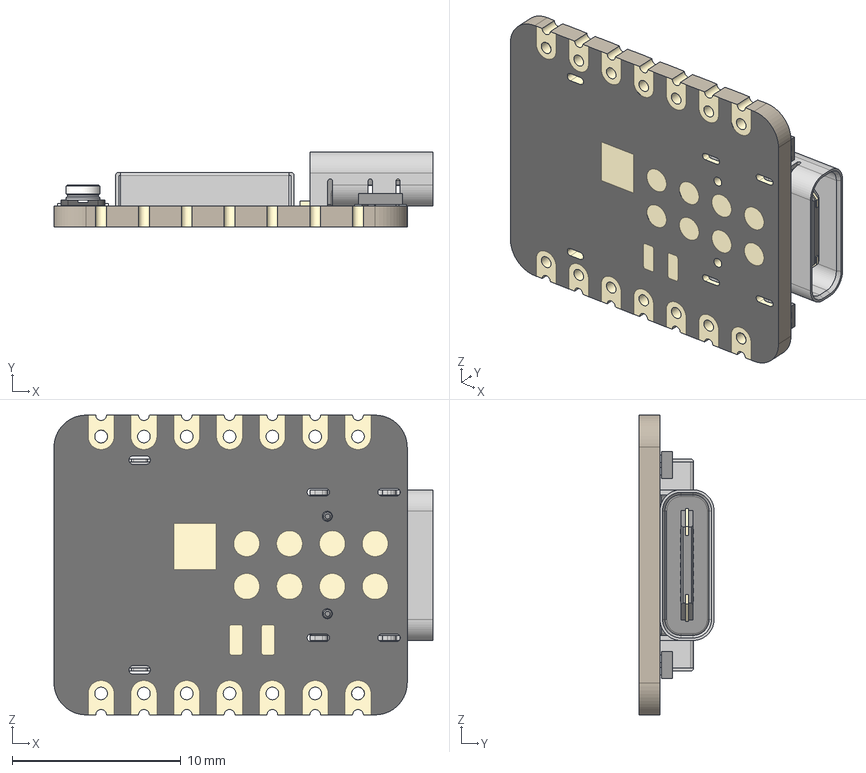
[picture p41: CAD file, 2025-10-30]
hardware/PCB/Components/ESP32s3/XIAO-ESP32S3 v2.step
22.5 x 4.46 x 17.8 mm
BOSS-EXTRUDE14_8_
BOSS-EXTRUDE7_4_
BOSS-EXTRUDE7_3_
BOSS-EXTRUDE14_4_
BOSS-EXTRUDE14_2_
BOSS-EXTRUDE14_11_
BOSS-EXTRUDE7_7_
BOSS-EXTRUDE14_9_
BOSS-EXTRUDE14_3_
BOSS-EXTRUDE14_7_
MIRROR2
BOSS-EXTRUDE14_5_
BOSS-EXTRUDE14_12_
BOSS-EXTRUDE7_8_
BOSS-EXTRUDE7_1_
BOSS-EXTRUDE14_10_
BOSS-EXTRUDE7_9_
BOSS-EXTRUDE14_6_
BOSS-EXTRUDE14_1_
BOSS-EXTRUDE7_6_
BOSS-EXTRUDE7_2_
CUT-EXTRUDE5
BOSS-EXTRUDE7_5_
Shield
Pins x 2
U.FL-R-SMT-1_10_ v1

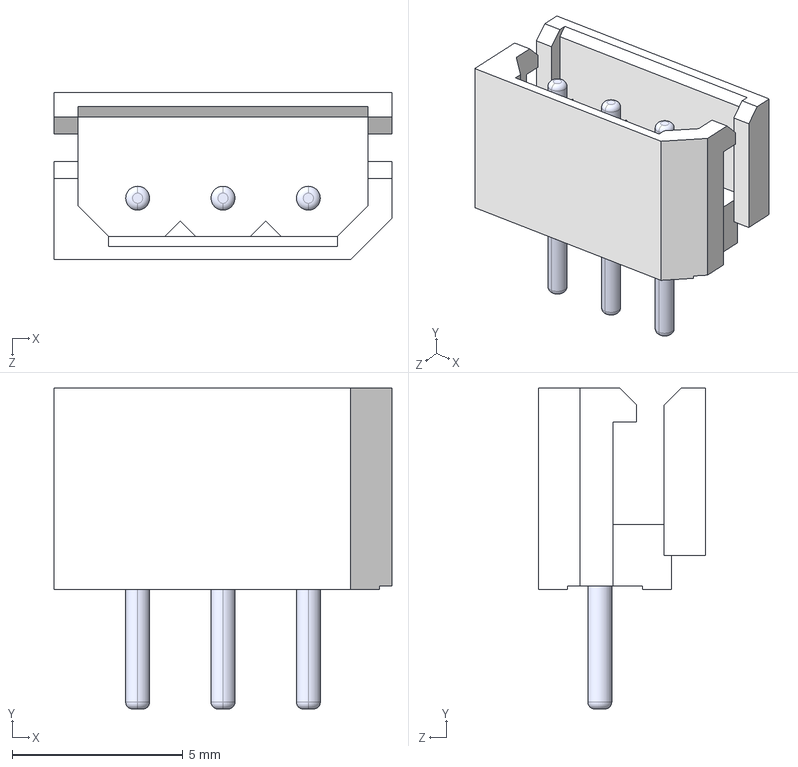
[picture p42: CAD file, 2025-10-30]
hardware/PCB/Components/Molex 220305025/22-03-5035.step
9.90 x 9.40 x 4.90 mm

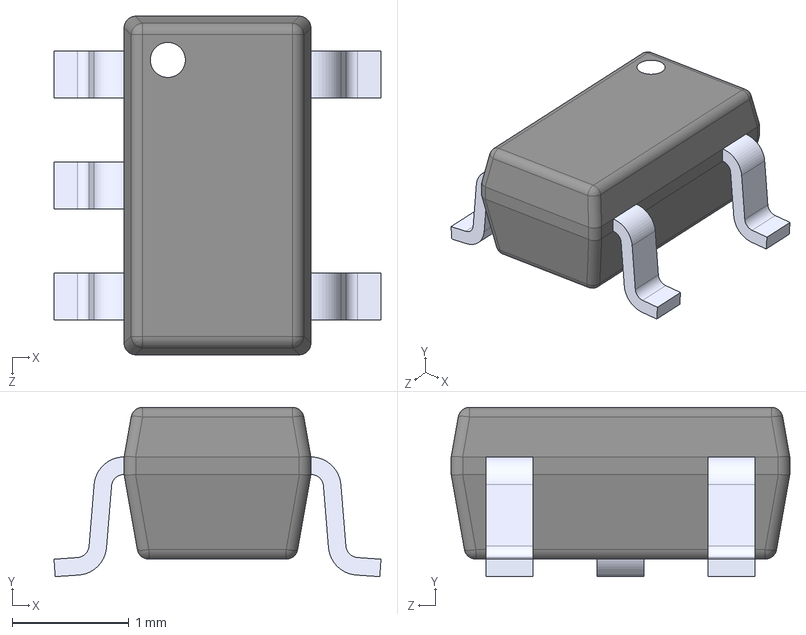
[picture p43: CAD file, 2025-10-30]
hardware/PCB/Components/SN74LVC1G125DBVR/SN74LVC1G125DBVR.step
2.80 x 1.45 x 2.90 mm

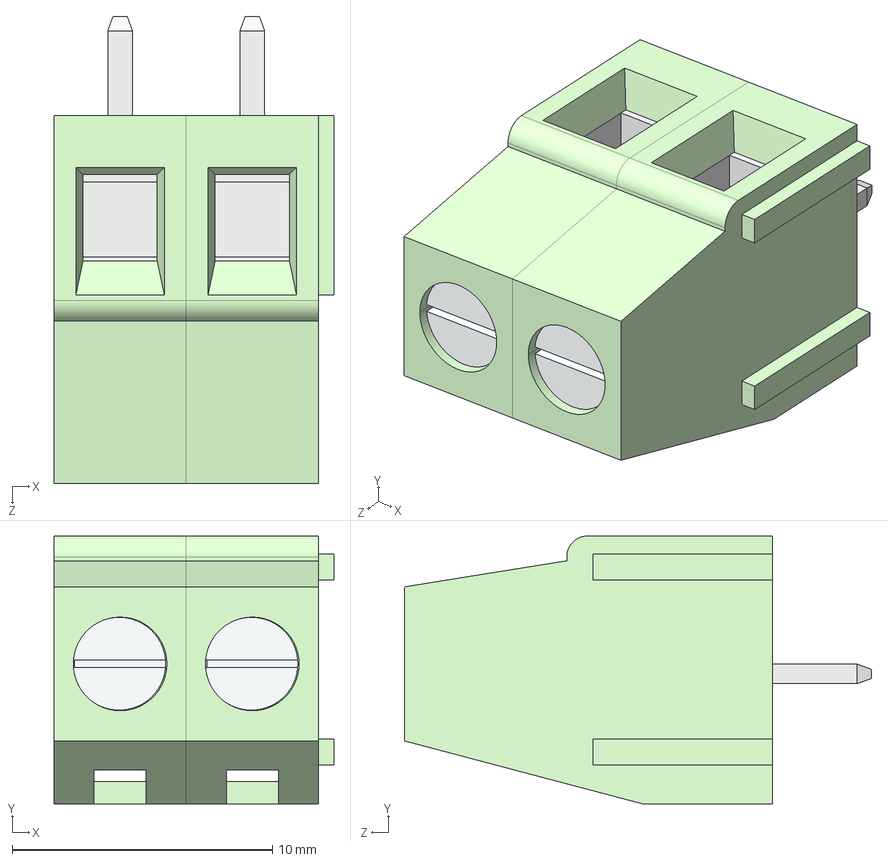
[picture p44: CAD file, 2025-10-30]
hardware/PCB/Components/terminal block 3d/KF128-5.08-2P.STEP
10.8 x 10.3 x 18.0 mm
KF128-5.08 x 2

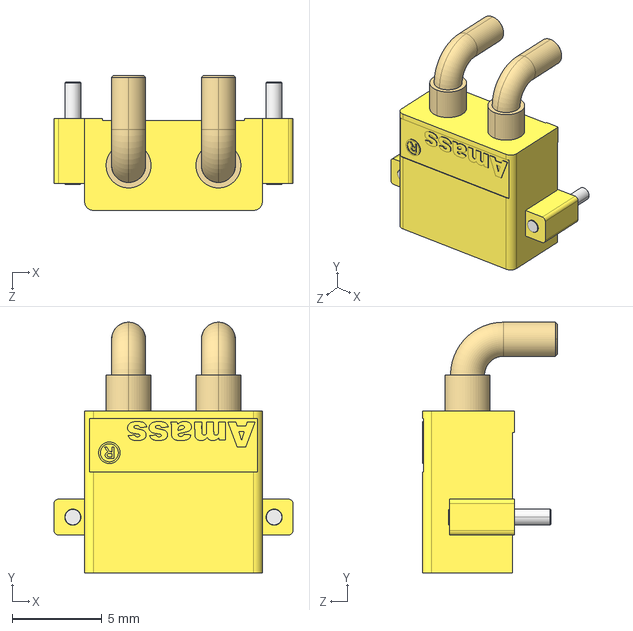
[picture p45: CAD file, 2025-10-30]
hardware/PCB/Components/XT30PW-M/3D/XT30PW-M.stp
13.3 x 13.9 x 7.50 mm

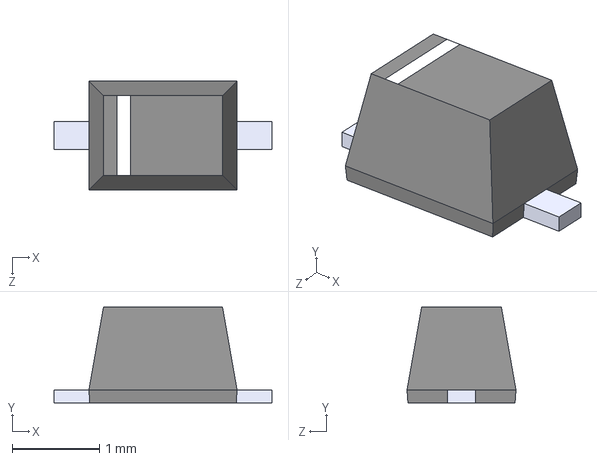
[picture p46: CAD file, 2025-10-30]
hardware/PCB/Components/zener diode/BZT52B5V1S.step
2.50 x 1.10 x 1.25 mm

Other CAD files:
ros2/src/aero_hand_open_description/meshes/left_pinky_proximal_link.STL
hardware/CAD/Molds/Finger_Distal_Mold.stp
hardware/CAD/Molds/Palm_Silicone_Mold_R.stp
hardware/CAD/Molds/Proximal_Pad_Mold.stp
hardware/CAD/Molds/Thumb_Distal_Pad_Mold.stp
hardware/PCB/Components/ESP32s3/XIAO ESP32S3 3D.stp
hardware/PCB/Components/rightanglemolex/22057035.step
ros2/src/aero_hand_open_description/meshes/left_base_link.STL
ros2/src/aero_hand_open_description/meshes/left_index_distal_link.STL
ros2/src/aero_hand_open_description/meshes/left_index_middle_link.STL
ros2/src/aero_hand_open_description/meshes/left_index_proximal_link.STL
ros2/src/aero_hand_open_description/meshes/left_index_tip_link.STL
ros2/src/aero_hand_open_description/meshes/left_middle_distal_link.STL
ros2/src/aero_hand_open_description/meshes/left_middle_middle_link.STL
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

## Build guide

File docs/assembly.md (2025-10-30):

# Assembly Instructions

This page contains the complete assembly instructions for the Aero Hand.

## View Instructions

You can view the assembly instructions PDF below, or [download it directly](./Assembly_Instructions.pdf).

<div style={{position: 'relative', width: '100%', height: '800px', border: '1px solid #ccc', borderRadius: '4px', overflow: 'hidden'}}>
  <iframe
    src={require('./Assembly_Instructions.pdf').default}
    style={{width: '100%', height: '100%', border: 'none'}}
    title="Assembly Instructions PDF"
  />
</div>

## Download

If the embedded viewer doesn't work in your browser, you can [download the PDF file here](./Assembly_Instructions.pdf).

---

:::tip
If you have any questions during assembly, please reach out to our community on [Discord](https://discord.gg/ZQKWK7NebQ).
:::

<div align="center">

Made with ❤️ by **TetherIA Robotics**

</div>

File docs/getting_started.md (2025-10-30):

# First-Time Setup
## ⚙️ Installation

The SDK is currently tested for Python 3.10 and above.

### 📦 Install via pip

```bash
pip install aero-hand-sdk
```

### 🧩 Install from source (editable mode)

1. Clone the repository to your local machine:
   ```bash
   git clone https://github.com/TetherIA/aero-open-sdk.git
   ```

2. Navigate to the cloned repository directory:
   ```bash
   cd aero-open-sdk
   ```

3. Install the package in editable mode:
   ```bash
   pip install -e .
   ```

---

## 🖥️ GUI — Aero Hand Open Control App

Launch the GUI from a terminal after installation:

```bash
aero-open-gui
```

> If your system can’t find the command, ensure your Python environment’s scripts directory is on PATH and that the package was installed into the active environment.

<div align="center">
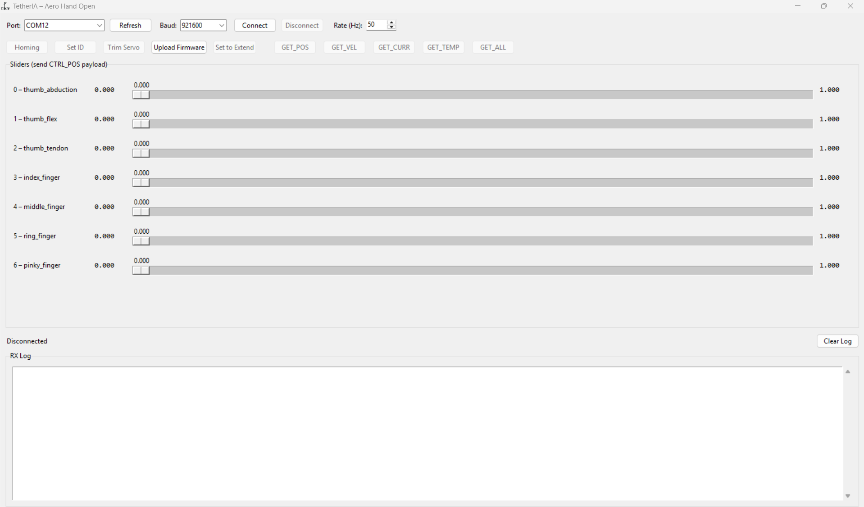
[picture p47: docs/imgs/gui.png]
Screenshot of GUI
  
</div>

### 🧩 First‑Time Setup: Uploading Firmware

To upload firmware to your Aero Hand device:

1. **Refresh all ports** in the GUI to detect connected devices.
2. If multiple ports are listed, identify the port for your ESP device:
  - On **Windows**, it is usually a **COM** port (e.g., COM3, COM12).
  - On **Linux**, look for `/dev/ttyACM0`, `/dev/ttyACM1`, etc.
3. Select the correct port and press the **Upload Firmware** button.
4. A dialog box will open—navigate to and select the appropriate firmware `.bin` file (`firmware_righthand.bin` or `firmware_lefthand.bin`).
5. The tool will upload the `.bin` file to the device at offset address **0x10000**.
6. On successful upload, you will see a confirmation message in the GUI.

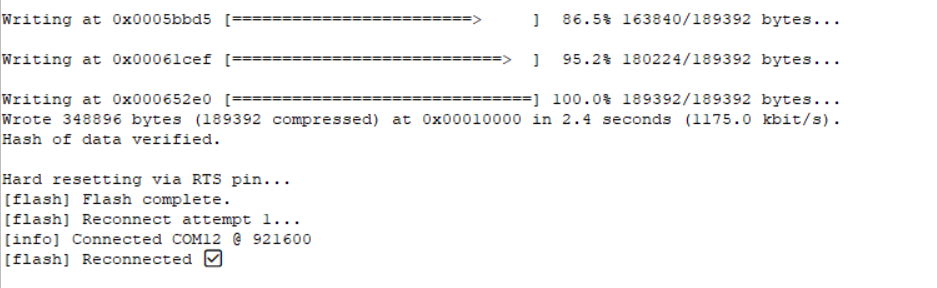
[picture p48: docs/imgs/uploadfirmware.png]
uploading Firmware


#### Notes & Troubleshooting

1. If you encounter errors, first check that you have selected the correct COM port.
2. The tool uses **esptool version 5 or greater**. Older versions may not work, as they use `write_flash` instead of `write-flash`.
3. After flashing, the tool will attempt to reconnect to the ESP automatically (up to 3 attempts). Usually, it connects on the first try. If not, refresh your ports and try again.
4. The firmware is uploaded to offset **0x10000**. Do not use merged or partition `.bin` files, as these may cause errors. Only use the provided bin files from the `aero-open-firmware` repository.

Next step is to set the servo IDs, see the next section below.

#### Setting Servo -IDs

1. **Power** the board with the 6V and connect USB.
2. **Connect exactly one servo** to the bus.
3. In the GUI, choose the correct **COM Port**, press **Connect**.
4. Click **Set ID** and assign the servo for the channel you’re wiring:
  * `0 → thumb_abduction_actuator`
  * `1 → thumb_flex_actuator`
  * `2 → thumb_tendon_actuator`
  * `3 → index_finger_actuator`
  * `4 → middle_finger_actuator`
  * `5 → ring_finger_actuator`
  * `6 → pinky_finger_actuator`
5. If the id is successfully set, You will receive an ACK in the RX bar below.
6. If you receive 65535 in oldid,new id and current as ACK , It indicates that the id is not successfully set.
7. After setting up the ID, you can move the responsible slider to make sure whether the actuator is moving or not.
8. Disconnect that servo, plug the next one, and **repeat** until all seven are assigned.

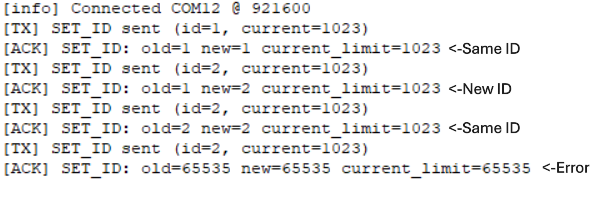
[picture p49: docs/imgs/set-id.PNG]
Setting Servo - IDs


##### Notes & Troubleshooting

1. Make sure that the board has power and exactly one servo is connected before setting the ID.
2. We recommend setting IDs for all servos in sequence (0–6). Any value apart from 0–6 will not be accepted.
3. For current limit, we recommend keeping it at the maximum (1023) and pressing OK—do not change this value unless necessary.
4. After setting the ID, you will receive the old ID, new ID, and current limit of the servo as confirmation.
5. If you receive 65535 in old ID, new ID, and current limit, this indicates that two or more servos are present and the Set ID mode will not proceed.
6. Once all IDs are Set, We recommend not to use this function once you are playing and training with the hand.

#### Trim Servo

When using Trim Servo:
First, you will be asked to enter the servo channel (0–6), which represents the sequence: thumb abduction, thumb flexion, thumb tendon, and the four fingers. Next, enter the degrees offset. We recommend making adjustments in steps of 10–20 degrees, then observe the effect using the sliders. If something unusual happens, you may need to perform the homing procedure again to reset the extend count to the baseline.

##### Left Hand Actuator Table
| Channel | Actuator Name | Extend Count | Grasp Count | Motion (°) | Direction | 
|---|---|---|---|---|---|
| 0 | Thumb Abduction | 2048 | 3186 | 100 | +1 | 
| 1 | Thumb Flexion | 865 | 2048 | 104 | -1 | 
| 2 | Thumb Tendon | 2980 | 0 | 262 | +1 | 
| 3 | Index Finger | 817 | 4095 | 288 | -1 | 
| 4 | Middle Finger | 817 | 4095 | 288 | -1 | 
| 5 | Ring Finger | 817 | 4095 | 288 | -1 |
| 6 | Pinky Finger | 817 | 4095 | 288 | -1 |

##### Right Hand Actuator Table

| Channel | Actuator Name | Extend Count | Grasp Count | Motion (°) | Direction | 
|---|---|---|---|---|---|
| 0 | Thumb Abduction | 2048 | 910 | 100 | -1 |
| 1 | Thumb Flexion | 3231 | 2048 | 104 | +1 |
| 2 | Thumb Tendon | 1115 | 4095 | 262 | -1 | 
| 3 | Index Finger | 3278 | 0 | 288 | +1 | 
| 4 | Middle Finger | 3278 | 0 | 288 | +1 |
| 5 | Ring Finger | 3278 | 0 | 288 | +1 |
| 6 | Pinky Finger | 3278 | 0 | 288 | +1 |

*Motion (°) is calculated as (Grasp Count - Extend Count) / 11.375*

##### Example: Trimming Right Hand Servo Channel 2 by +10 Degrees

Suppose you set +10 degrees trim for the right hand, servo channel 2 (Thumb Tendon Actuator):
- Original Extend Count: 1115
- Grasp Count: 4095
- Each degree corresponds to 11.375 counts.
- So, +10 degrees will update Extend Count to:
  
  1115 + (10 × 11.375) = 1228 (rounded to 1228)

- The new range of motion will be:
  
  4095 - 1228 = 2867 counts

This means the servo will now move through 2867 counts instead of the original 2980 counts which represent 262 degrees of motion and now it will move 252 degrees of total motion only, which will reduce the full range of motion and make it more tight. If you do in the opposite direction , It will increase the motion of servo which will loose the wire and may cause issues. Since , You cannot mofidy the grasp count of the servo, We recommned to go through this table before doing any changes.

Trim Servo

##### Notes & Troubleshooting
1. Do not enter values like 360 or -360 degrees, as this may completely change your control direction—please avoid this.
2. If the servo becomes too tight, try loosening it by entering degrees in the opposite direction to your last adjustment.
3. Use this function only when you want fine control over the servo's range of motion.
4. Disconnect power immediately if any actuator moves to an abrupt position and draws stall current (typically 1.3–1.5A).

### 🎛️ Top Bar Controls

* **Port**: Dropdown of available serial ports.
  Use **Refresh** to re‑scan if you plug/unplug devices.
* **Baud**: Serial speed. Default 921600 is typical for fast streaming and our firmware uses the same baudrate as well.
* **Connect / Disconnect**: Open or close the selected serial port.
* **Rate (Hz)**: How often the GUI streams **CTRL_POS** frames while you move sliders.
  **Recommended:** 50 Hz for smooth motion without saturating USB.

### 🧪 Action Buttons (left→right)

* **Homing** 🏠: Sends opcode `0x01` to run the on‑board homing routine.Any Other Input is ignored while homing is active; wait for ACK under a given timeout of 3minutes.
* **Set ID** 🆔: Guided flow to set a servo’s bus ID. Requires a **single** servo connected; the firmware verifies this before writing.
* **Trim Servo** ✂️: Fine‑tune alignment per channel. Enter **channel (0–6)** and **degrees offset** (±). The firmware adjusts/persists the channel’s `extend_count` in NVS so it survives reboots. Use small steps (±5–10°) and test.
* **Upload Firmware** ⬆️: Flash a `.bin` directly from the GUI. After selection, the board is reset into bootloader, the image is written, and the device restarts.
* **Set to Extend** 🔄: Sends a single **CTRL_POS** frame that sets **all channels to 0.000** (fully open / extend posture). Handy as a “panic open”.
* **GET_POS** 📍: Requests positions. Values are shown normalized **0.000 → 1.000**, computed from each channel’s `extend↔grasp` calibration (host 0..65535).
* **GET_VEL** 💨: Requests velocities of the actuator motions.
* **GET_CURR** 🔌: Requests currents in **mA**, **signed** — the **sign reflects motor direction** relative to the channel’s servo direction (use magnitude to gauge load).
* **GET_TEMP** 🌡️: Requests temperatures (°C) from each servo.
* **GET_ALL** 📦: Convenience burst that triggers **POS + VEL + CURR + TEMP** reads in one go and prints results to the log.
* **Set Speed** 🚀: Sets the speed limit for a selected servo ID (opcode `0x31`). This sets the maximum speed for that servo; by default, the speed is max and resets after reboot. The speed set here affects the max speed the motor moves during the position control mode, which is different from the speed control mode.
* **Set Torque** 💪: Sets the maximum torque limit for a selected servo ID (opcode `0x32`). This limits the maximum torque; by default, torque is max and resets after reboot. The torque set here affects the max torque the motor can apply during the position control mode, which is different from the torque control mode.

### 🧷 Sliders Panel (Center)

Each row controls a single actuator channel with a **normalized slider**:

* **0.000 → 1.000** maps linearly to the channel’s calibrated **extend ↔ grasp** range in 2 bytes and sent as 14 bytes payload using CTRL_POS Command.
* While you drag, the GUI streams **CTRL_POS** frames at the selected **Rate (Hz)**.
* Two small numeric readouts show the current command and (when polled) the latest normalized feedback.

**Channel map (top→bottom):** `thumb_abduction_actuator`, `thumb_flex_actuator`, `thumb_tendon_actuator`, `index_finger_actuator`, `middle_finger_actuator`, `ring_finger_actuator`, `pinky_finger_actuator`.

### 📟 Status & Logs (Bottom)

* **Status bar** (left): Connection state (e.g., *Disconnected*, *COM12 @ 921600*), last error, and homing/flash progress messages.
* **RX Log**: Text console of responses/telemetry. Useful for debugging, verifying opcodes, and viewing GET_* results.
* **Clear Log**: Clears the RX Log display (does not affect device state).

### 🧰 Tips & Tricks

* **Port not listed?** Click **Refresh**; check drivers, cables, and that no other app is holding the port.
* **Set‑ID fails?** Ensure only one servo is connected and the servo rail is powered.
* **No motion?** Verify you selected the correct hand build (left/right), try **Set to Extend**, then move sliders slowly.
* **Choppy control?** Lower **Rate (Hz)** or close other serial/USB‑heavy apps.

### 🐍 Python Control & Examples

Prefer scripting or automation? Use the Python SDK to send the same 16‑byte frames programmatically and log telemetry.

* Import the high‑level class (e.g., `AeroHand`) and browse **examples** in this repo’s `examples/` folder.
* The GUI and SDK speak the **same protocol**, so your scripts and the app can be used interchangeably during development.

<div align="center">

Made with ❤️ by **TetherIA Robotics**

</div>

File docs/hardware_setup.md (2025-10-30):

# Hardware Setup

This page contains the complete hardware setup connections guide for the Aero Hand.

### 🚀 **Option 1 (RECOMMENDED) - Plug & Play Solution**
> **⭐ EASIEST & FASTEST WAY TO GET STARTED**

**Buy our custom PCBs** (described above) from our [website](https://shop.tetheria.ai/products/pcbs) for a **plug-and-play solution**. 

✅ **Benefits:**
- **Zero soldering required** - just plug and play
- **Professional quality** - tested and verified PCBs
- **Self-explanatory connections** - cable connections are straightforward
- **Maximum reliability** - optimized for all motor currents
- **Time-saving** - get your hand running in minutes, not hours

🔗 **[Order PCBs Now →](https://shop.tetheria.ai/products/pcbs)**

### Option 2
If you prefer to manufacture and solder the PCBs yourself, all files and resources for self-manufacturing are provided in the [PCB](<https://github.com/TetherIA/aero-hand-open/tree/main/hardware/PCB>) folder.

### Option 3 
Use off-the-shelf protoboard and connectors (Molex 3-pin, JST) to manually wire and control the servos. This method requires careful soldering and wire management, and may not support maximum current for all motors. You will need:
- Protoboard
- Molex 3-pin connectors (for servos)
- JST connectors
- Servo cables
- Soldering tools

Once you have everything , You can refer to our guide under **Hardware Setup Guide** folder . Or you can also take a look at the next steps.

Step 1: Solder Pin Headers to ESP and do connections to TTLinker Mini Board.
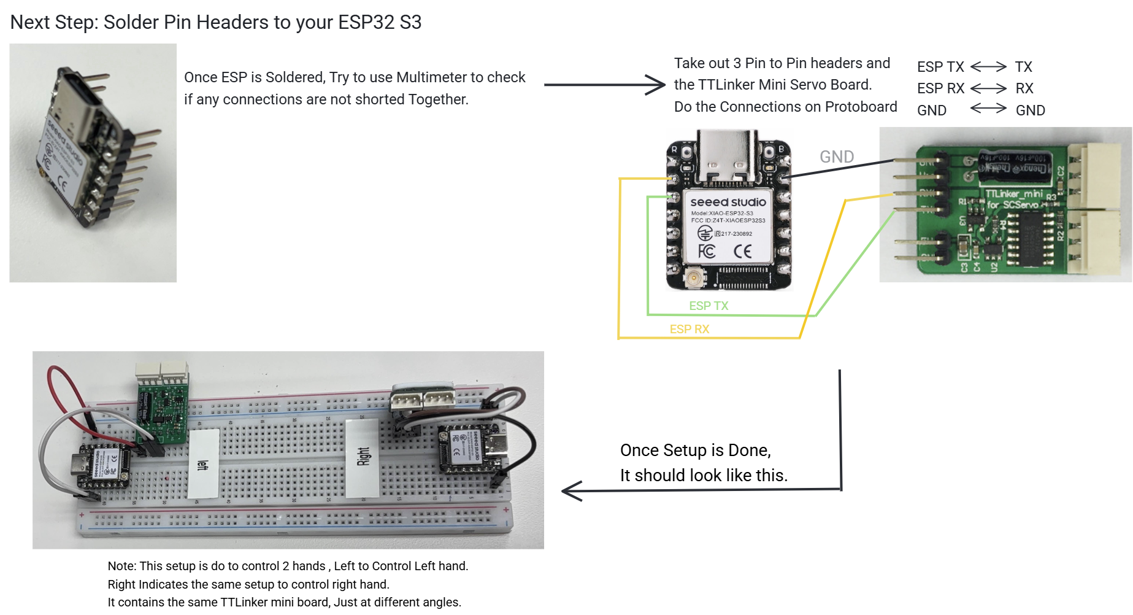
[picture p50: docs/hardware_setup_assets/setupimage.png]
Setup Image


Step2: Connect 6V 10A regulated power supply like below image
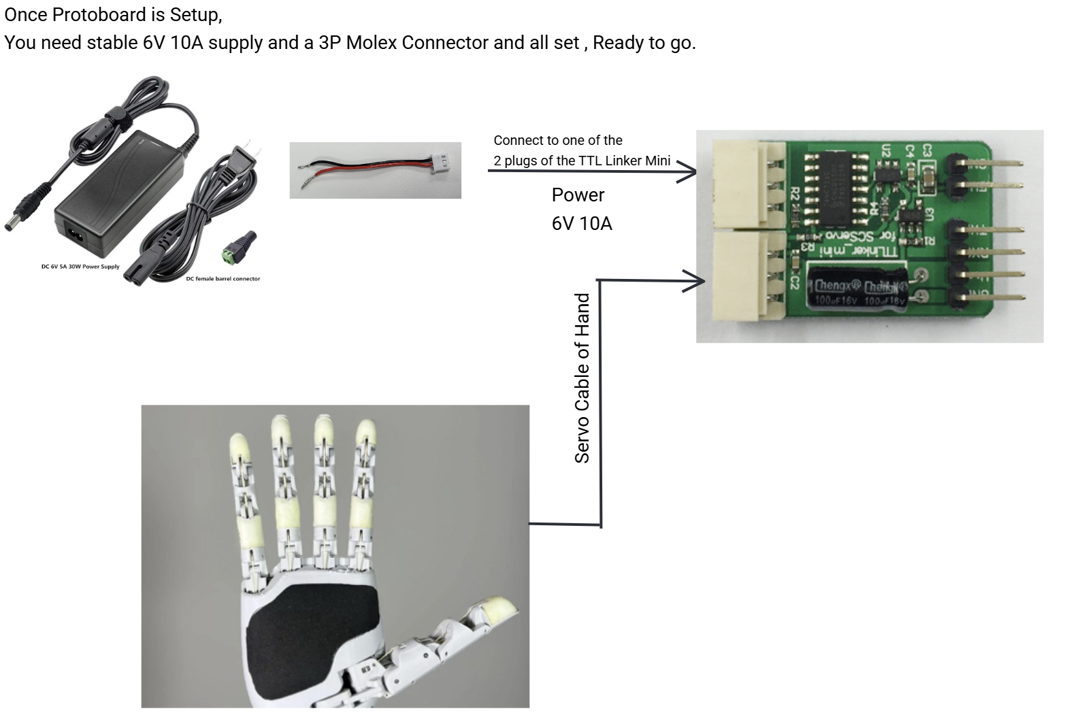
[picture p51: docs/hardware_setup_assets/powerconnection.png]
Power Setup


Step3: Once your setup is ready, It will look something like this.
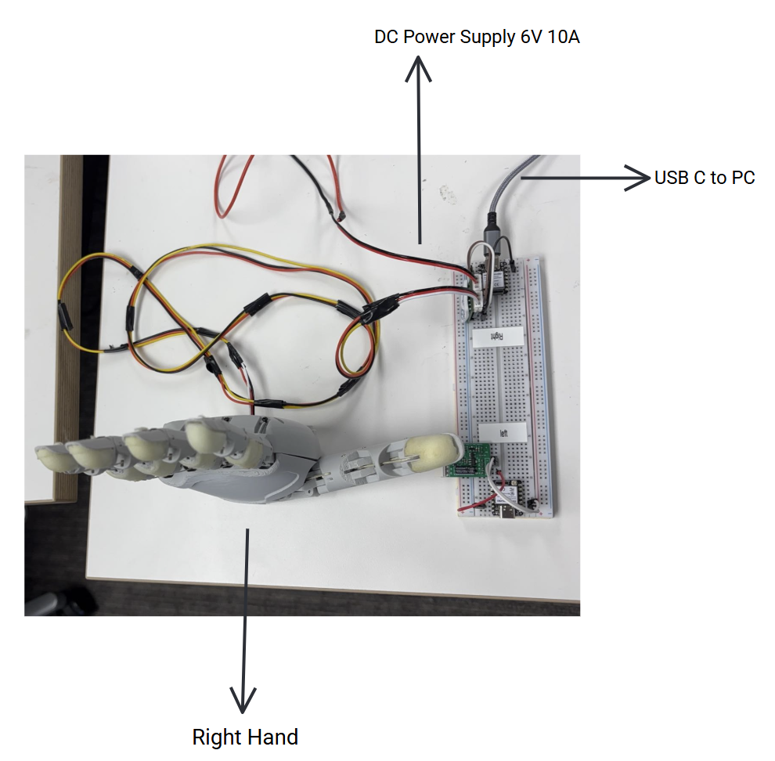
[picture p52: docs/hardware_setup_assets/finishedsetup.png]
Finished setup1


**OR** if you want to do soldered connections on a board directly instead of using a protoboard, then your connections will look like this.

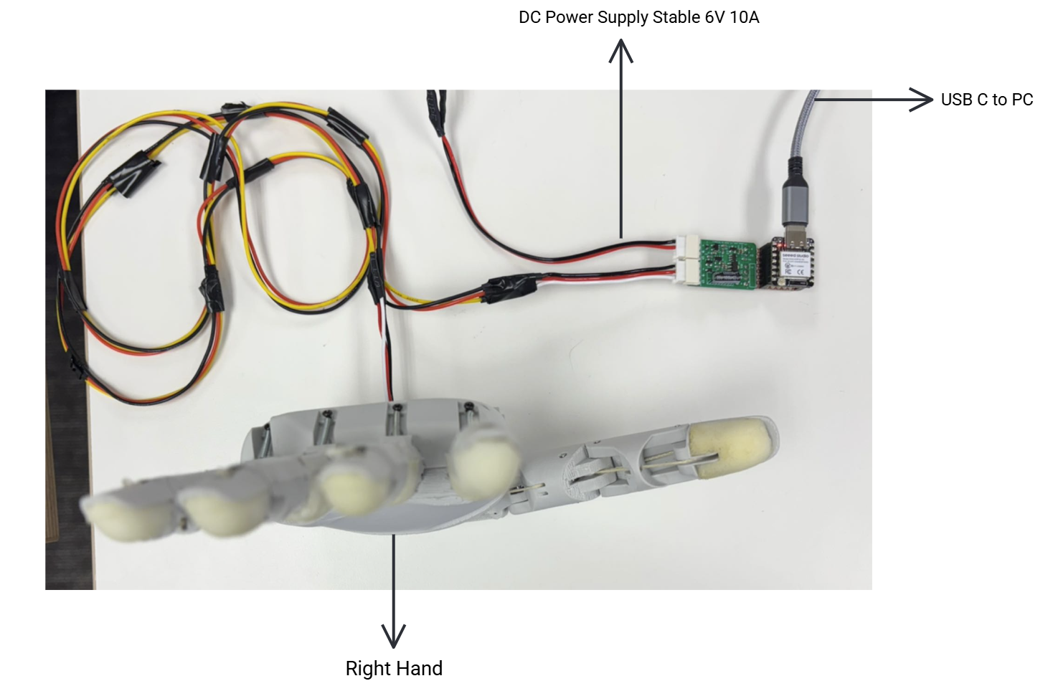
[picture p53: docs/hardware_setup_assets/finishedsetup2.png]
Finished Setup2


**OR** it will looks like this, depending on how you soldered it.

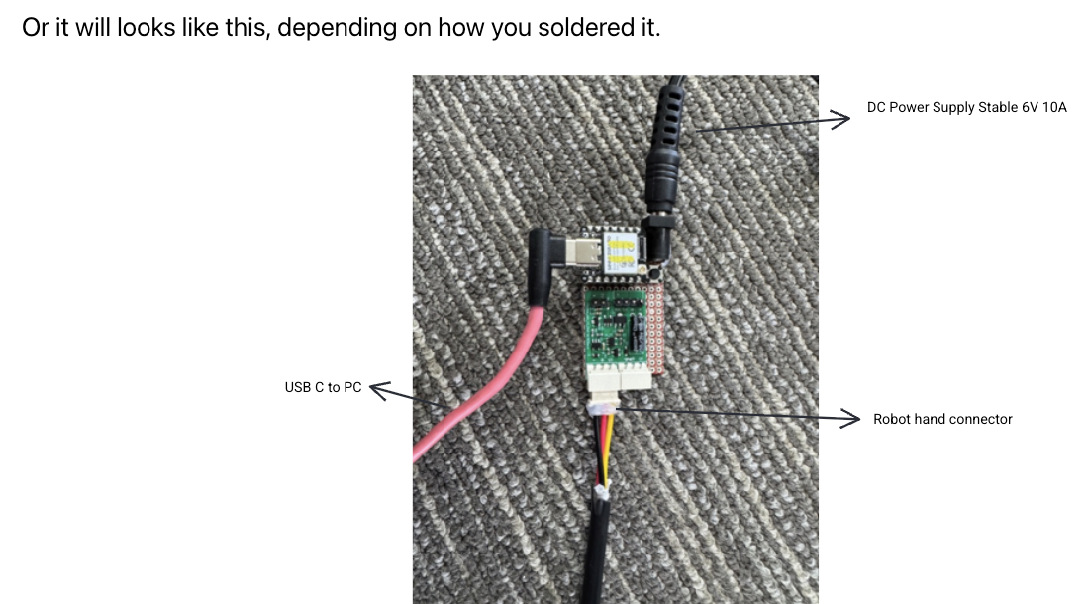
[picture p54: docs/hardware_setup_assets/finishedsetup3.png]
Finished Setup3


:::tip
If you have any questions, please reach out to our community on [Discord](https://discord.gg/ZQKWK7NebQ).
:::

<div align="center">

Made with ❤️ by **TetherIA Robotics**

</div>

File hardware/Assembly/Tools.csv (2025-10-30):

We reccomend using the tools below to build the hand yourself, you may be able to build it without the tools but it will be more difficult
Tool | Link | Function
Floss tool | https://www.amazon.com/WLLHYF-Floss-Multifunctional-Deep-Clean/dp/B0C374TM1X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 | This makes routing cables super easy, without it assembly becomes challenging (still possible)
Superglue | amazon.com/Loctite-Control-4-Gram-Bottle-1739050/dp/B00ELV2D0Y/ref=sr_1_9?crid=1NFLQOVYY0MOX&dib=eyJ2IjoiMSJ9.VzOtkLFDgnBq1uZQL8f-HT2o_EvceGCmp4LROwN_uk56eIWVbzoqeGGHwIJwuwP_YI6xcWLa-PVokqch6YbsSC7L2sY3fWMXFEmwlYZavI5gXuBSTtcDbyyXJZxPe30XBdPngJO50Lze-5PnihTlHJtQzbdwN6Vc7rLz3y4HaUWFynBGrQPEZrLrXeHC5qpVjWAuVN6X1sYZl8um77B7w0ldhaHHVJ-nGq9C3WC6YYs.ADFwEfGRX7VMNHP7zmvK0ciRAjY7Z0QdbZu57QWEZ2Y&dib_tag=se&keywords=super+glue+gel&qid=1758236840&sprefix=super+glue+ge%2Caps%2C213&sr=8-9 | Secure pins if they are too loose, use instead of loctite on fasteners (not reccomended)
Silicone Adhesive | amazon.com/ALECPEA-30g-Silicone-Glue-Fast-Bonding/dp/B0CHJND26L/ref=sr_1_3?crid=804CEQRU75C3&dib=eyJ2IjoiMSJ9.KkdHiRmeXmoAr1pJMSARoVfNyF1UJ0G4GOxyLhkzwYl1huPajPaqQdMRN89bh59-E0g6UrwtDCajPMEgNJoff40-13NOzZWuAgmtSwF6GGJS_pB9nFcJ3DV4np9QXwtvG2vuAUxvYNhfX9MdChr2Fui7YzdRi4nXAosf7mnEIJgs1p_E2moGD2O519lCALQPdhjXZib6-H5nJ8DqU8EUjxpZvceSndtldi10ZMfVDv4.qmnubKoVOI6RoOEgyxagHz5k_m9iis7s4srMcdAuxKc&dib_tag=se&keywords=silicone+glue&qid=1759859278&sprefix=silicone+glue%2Caps%2C184&sr=8-3 | required for bonding silicone to plastic
Files/Sandpaper | https://www.amazon.com/Hardened-Strength-Barrette-Crossing-Equaling/dp/B07PPYWSCY | Use to clean up 3D prints
Wire Cutters | amazon.com/HongWay-Cutters-Cutting-Electronics-5-inches/dp/B09W8YYJD6/ref=sr_1_3?crid=3IW7FKEKJ1507&dib=eyJ2IjoiMSJ9.3v91NM1r9OYyQFU-OQ7yqH6oYIAzWQ7Zcg2IBMWlreMcb2fBTScDE62j71CaKSdXqkvbRDxpL1As5Lqy1k2iiXvI78JlQxpR0c45vidJxKdg8yLach6cAnp07A0O0a01k3dkXCXpm7egDxa6wcTRkRH005kixvTCjFaSmBaRf2KV7pOYPvVzeN5VEreb9YiwO1JNf2AIOUNbbbn5WMLhBs6l5PKmZ2yXt3puInAEYa8.Vew8ePZ2H5D1x_YUtwJ3dFdrjLW-yKj1NAdbtv0Wdr8&dib_tag=se&keywords=flush+cutters&qid=1758236951&sprefix=flsuh+currer%2Caps%2C164&sr=8-3 | Use to clean up 3D prints
Jewelry drill kit | amazon.com/Vise-Hand-Drill-Jewelry-Making/dp/B098CF3VMM/ref=sr_1_5?crid=14VZV4CUOZE05&dib=eyJ2IjoiMSJ9.cB1t0N7_W1MXwUNYf4FGdoyPPi4If-c6eGxvrQmQaZLn17n0UI_mH0B7q4P80thHpkCyGSLsaXHgNHUctejxMovLXCZ2RN5MSKh1iQaQEtvdgEIEGok_oC9ctMSMiag3BwMRbxj-fyKDZw76k720JhPWwrPbXArxPYtlfKsfLKIQUv-U4wpQT1F0fQf7aNHCyErwsJnXPVumfGfgaxDGle3RJOAfl9J2y-bwXh-B1ck.3zxrETT7iHDFkvhJUo8ztnyfkATN-093DLzMpGoixL0&dib_tag=se&keywords=jewelry+drill+kit&qid=1758236968&sprefix=jewelry+drill+ki%2Caps%2C168&sr=8-5 | Drill out 3D printed part holes
2.1mm drill | https://www.amazon.com/HARFINGTON-Drilling-Stainless-Plastic-Materials/dp/B0D542KTPL | 2.1mm drill
Sharp Scissors/razor blade | - | For cutting vectran/kevlar/cable
Tweezers | - | To help fish cable through certain features
Torx Screwdriver set | - | for fasteners
Philips screwdriver set | - | for fasteners
Flexible driver extension | - | Helps to reach hard to reach bolts without stripping screws
3D printer | - | Necessary to print your own parts
Soldering Equipment | - | For heat inserts and if making soldered wire connections
Tape measure | - | For measuring cable lengths
Needle nose pliers | - | Helpful when installing pins
Sharpie/paint marker | - | for marking servo numbers and cable lengths

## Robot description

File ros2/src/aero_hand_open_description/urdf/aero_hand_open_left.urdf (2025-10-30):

<?xml version='1.0' encoding='utf-8'?>
<robot name="aero_hand_open_left">
  <link name="left_base_link">
    <inertial>
      <origin xyz="0.001091225077 -0.00334946624 0.04898559343" rpy="0 -0 0" />
      <mass value="0.303576106034272" />
      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
    </inertial>
    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
  </link>
  <link name="left_t_link">
    <inertial>
      <origin xyz="-0.0008835251048 -0.0017040798 0.008310282404" rpy="0 -0 0" />
      <mass value="0.00833536405562315" />
      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
    </inertial>
    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
  </link>
  <joint name="left_thumb_cmc_abd" type="revolute">
    <origin xyz="0.028112 0.0145 0.025363" rpy="1.2217 -0 1.57" />
    <parent link="left_base_link" />
    <child link="left_t_link" />
    <axis xyz="-0 1 -0" />
    <limit lower="0" upper="1.7453" effort="0" velocity="0" />
  </joint>
  <link name="left_thumb_mcp_link">
    <inertial>
      <origin xyz="-1.9848e-07 -0.00075445 0.014668" rpy="0 -0 0" />
      <mass value="0.008207" />
      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
    </inertial>
    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
  </link>
  <joint name="left_thumb_cmc_flex" type="revolute">
    <origin xyz="-0.003475 -0.003808 0.019656" rpy="-0.1325 -0.17906 -0.26195" />
    <parent link="left_t_link" />
    <child link="left_thumb_mcp_link" />
    <axis xyz="-1 -0 -0" />
    <limit lower="0" upper="0.9599" effort="0" velocity="0" />
  </joint>
  <link name="left_thumb_proximal_link">
    <inertial>
      <origin xyz="7.9121e-09 -0.001007 0.011955" rpy="0 -0 0" />
      <mass value="0.005471" />
      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
    </inertial>
    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
  </link>
  <joint name="left_thumb_mcp" type="revolute">
    <origin xyz="0 -0.0033822 0.035848" rpy="0 -0 0" />
    <parent link="left_thumb_mcp_link" />
    <child link="left_thumb_proximal_link" />
    <axis xyz="-1 -0 -0" />
    <limit lower="0" upper="1.5708" effort="0" velocity="0" />
  </joint>
  <link name="left_thumb_distal_link">
    <inertial>
      <origin xyz="-6.4155e-07 0.0011983 0.010377" rpy="0 -0 0" />
      <mass value="0.0032396" />
      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
    </inertial>
    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
  </link>
  <joint name="left_thumb_ip" type="revolute">
    <origin xyz="0 -0.002206 0.029919" rpy="0 -0 0" />
    <parent link="left_thumb_proximal_link" />
    <child link="left_thumb_distal_link" />
    <axis xyz="-1 -0 -0" />
    <limit lower="0" upper="1.5708" effort="0" velocity="0" />
  </joint>
  <link name="left_thumb_tip_link">
    <inertial>
      <origin xyz="2.2383e-07 0.010203 -0.013939" rpy="0 -0 0" />
      <mass value="0.00086967" />
      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
    </inertial>
    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
  </link>
  <joint name="left_thumb_tip" type="fixed">
    <origin xyz="0 -0.0059474 0.031823" rpy="0 -0 0" />
    <parent link="left_thumb_distal_link" />
    <child link="left_thumb_tip_link" />
    <axis xyz="-0 -0 -0" />
  </joint>
  <link name="left_index_proximal_link">
    <inertial>
      <origin xyz="4.305299929e-08 0.002455960396 0.01911425149" rpy="0 -0 0" />
      <mass value="0.00720026836301954" />
      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
    </inertial>
    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
  </link>
  <joint name="left_index_mcp_flex" type="revolute">
    <origin xyz="0.030626 0.0011782 0.10542" rpy="0 0.05236 0.034907" />
    <parent link="left_base_link" />
    <child link="left_index_proximal_link" />
    <axis xyz="-1 -0 -0" />
    <limit lower="0" upper="1.5708" effort="0" velocity="0" />
  </joint>
  <link name="left_index_middle_link">
    <inertial>
      <origin xyz="-6.479857529e-09 0.0003632696147 0.008760790088" rpy="0 -0 0" />
      <mass value="0.00276150356687874" />
      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
    </inertial>
    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
  </link>
  <joint name="left_index_pip" type="revolute">
    <origin xyz="0 0.0014554 0.043" rpy="0 -0 0" />
    <parent link="left_index_proximal_link" />
    <child link="left_index_middle_link" />
    <axis xyz="-1 -0 -0" />
    <limit lower="0" upper="1.5708" effort="0" velocity="0" />
  </joint>
  <link name="left_index_distal_link">
    <inertial>
      <origin xyz="3.346719613e-07 0.001202241437 0.007772347078" rpy="0 -0 0" />
      <mass value="0.00183663667769987" />
      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
    </inertial>
    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
  </link>
  <joint name="left_index_dip" type="revolute">
    <origin xyz="0 0 0.022" rpy="0 -0 0" />
    <parent link="left_index_middle_link" />
    <child link="left_index_distal_link" />
    <axis xyz="-1 -0 -0" />
    <limit lower="0" upper="1.5708" effort="0" velocity="0" />
  </joint>
  <link name="left_index_tip_link">
    <inertial>
      <origin xyz="2.379809052e-08 0.007053532731 -0.01244340812" rpy="0 -0 0" />
      <mass value="0.000390243409160287" />
      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
    </inertial>
    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
  </link>
  <joint name="left_index_tip" type="fixed">
    <origin xyz="0 -0.003512 0.026776" rpy="0 -0 0" />
    <parent link="left_index_distal_link" />
    <child link="left_index_tip_link" />
    <axis xyz="-0 -0 -0" />
  </joint>
  <link name="left_middle_proximal_link">
    <inertial>
      <origin xyz="3.048637389e-08 0.002455964113 0.01911425441" rpy="0 -0 0" />
      <mass value="0.0072002618370038" />
      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
    </inertial>
    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
  </link>
  <joint name="left_middle_mcp_flex" type="revolute">
    <origin xyz="0.0075 0 0.106" rpy="0 -0 0" />
    <parent link="left_base_link" />
    <child link="left_middle_proximal_link" />
    <axis xyz="-1 -0 -0" />
    <limit lower="0" upper="1.5708" effort="0" velocity="0" />
  </joint>
  <link name="left_middle_middle_link">
    <inertial>
      <origin xyz="-2.85973602e-09 0.0003632643325 0.008760781465" rpy="0 -0 0" />
      <mass value="0.00276150069139886" />
      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
    </inertial>
    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
  </link>
  <joint name="left_middle_pip" type="revolute">
    <origin xyz="0 0.0014554 0.043" rpy="0 -0 0" />
    <parent link="left_middle_proximal_link" />
    <child link="left_middle_middle_link" />
    <axis xyz="-1 -0 -0" />
    <limit lower="0" upper="1.5708" effort="0" velocity="0" />
  </joint>
  <link name="left_middle_distal_link">
    <inertial>
      <origin xyz="1.252059834e-07 0.001202236412 0.007773249197" rpy="0 -0 0" />
      <mass value="0.00183690507488675" />
      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
    </inertial>
    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
  </link>
  <joint name="left_middle_dip" type="revolute">
    <origin xyz="0 0 0.022" rpy="0 -0 0" />
    <parent link="left_middle_middle_link" />
    <child link="left_middle_distal_link" />
    <axis xyz="-1 -0 -0" />
    <limit lower="0" upper="1.5708" effort="0" velocity="0" />
  </joint>
  <link name="left_middle_tip_link">
    <inertial>
      <origin xyz="-7.964623181e-08 0.007053282745 -0.0124432894" rpy="0 -0 0" />
      <mass value="0.00039026895252879" />
      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
    </inertial>
    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
  </link>
  <joint name="left_middle_tip" type="fixed">
    <origin xyz="0 -0.003512 0.026776" rpy="0 -0 0" />
    <parent link="left_middle_distal_link" />
    <child link="left_middle_tip_link" />
    <axis xyz="-0 -0 -0" />
  </joint>
  <link name="left_ring_proximal_link">
    <inertial>
      <origin xyz="-2.242193882e-08 0.002455968698 0.01911421726" rpy="0 -0 0" />
      <mass value="0.00720026581090036" />
      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
    </inertial>
    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
  </link>
  <joint name="left_ring_mcp_flex" type="revolute">
    <origin xyz="-0.015626 0.0011782 0.10542" rpy="0 -0.05236 -0.034907" />
    <parent link="left_base_link" />
    <child link="left_ring_proximal_link" />
    <axis xyz="-1 -0 -0" />
    <limit lower="0" upper="1.5708" effort="0" velocity="0" />
  </joint>
  <link name="left_ring_middle_link">
    <inertial>
      <origin xyz="-1.057681042e-08 0.0003632676921 0.008760783581" rpy="0 -0 0" />
      <mass value="0.00276150640462905" />
      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
    </inertial>
    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
  </link>
  <joint name="left_ring_pip" type="revolute">
    <origin xyz="0 0.0014554 0.043" rpy="0 -0 0" />
    <parent link="left_ring_proximal_link" />
    <child link="left_ring_middle_link" />
    <axis xyz="-1 -0 -0" />
    <limit lower="0" upper="1.5708" effort="0" velocity="0" />
  </joint>
  <link name="left_ring_distal_link">
    <inertial>
      <origin xyz="4.412362485e-07 0.001202061168 0.00777174807" rpy="0 -0 0" />
      <mass value="0.00183637337497735" />
      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
    </inertial>
    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
  </link>
  <joint name="left_ring_dip" type="revolute">
    <origin xyz="0 0 0.022" rpy="0 -0 0" />
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

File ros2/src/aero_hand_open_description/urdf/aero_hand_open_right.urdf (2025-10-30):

<?xml version="1.0" encoding="utf-8"?>
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
<robot name="aero_hand_open_right">
  <link name="right_base_link">
    <inertial>
      <origin xyz="0.00109122507694746 0.00334946623951281 0.0489855934276007" rpy="0 0 0" />
      <mass value="0.303576106034272" />
      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
    </inertial>
    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
  </link>
  <link name="right_t_link">
    <inertial>
      <origin xyz="-0.000883525104759189 0.00170407980029484 0.00831028240403424" rpy="0 0 0" />
      <mass value="0.00833536405562315" />
      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
    </inertial>
    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
  </link>
  <joint name="right_thumb_cmc_abd" type="revolute">
    <origin xyz="0.028112 -0.0145 0.025363" rpy="-1.2217 -0.0 -1.57" />
    <parent link="right_base_link" />
    <child link="right_t_link" />
    <axis xyz="0 1 0" />
    <limit lower="0" upper="1.7453" effort="0" velocity="0" />
  </joint>
  <link name="right_thumb_mcp_link">
    <inertial>
      <origin xyz="-1.9848E-07 0.00075445 0.014668" rpy="0 0 0" />
      <mass value="0.008207" />
      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
    </inertial>
    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
  </link>
  <joint name="right_thumb_cmc_flex" type="revolute">
    <origin xyz="-0.003475 0.003808 0.019656" rpy="0.1325 -0.17906 0.26195" />
    <parent link="right_t_link" />
    <child link="right_thumb_mcp_link" />
    <axis xyz="1 0 0" />
    <limit lower="0" upper="0.9599" effort="0" velocity="0" />
  </joint>
  <link name="right_thumb_proximal_link">
    <inertial>
      <origin xyz="7.9121E-09 0.001007 0.011955" rpy="0 0 0" />
      <mass value="0.005471" />
      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
    </inertial>
    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
  </link>
  <joint name="right_thumb_mcp" type="revolute">
    <origin xyz="0 0.0033822 0.035848" rpy="0 0 0" />
    <parent link="right_thumb_mcp_link" />
    <child link="right_thumb_proximal_link" />
    <axis xyz="1 0 0" />
    <limit lower="0" upper="1.5708" effort="0" velocity="0" />
  </joint>
  <link name="right_thumb_distal_link">
    <inertial>
      <origin xyz="-6.4155E-07 -0.0011983 0.010377" rpy="0 0 0" />
      <mass value="0.0032396" />
      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
    </inertial>
    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
  </link>
  <joint name="right_thumb_ip" type="revolute">
    <origin xyz="0 0.002206 0.029919" rpy="0 0 0" />
    <parent link="right_thumb_proximal_link" />
    <child link="right_thumb_distal_link" />
    <axis xyz="1 0 0" />
    <limit lower="0" upper="1.5708" effort="0" velocity="0" />
  </joint>
  <link name="right_thumb_tip_link">
    <inertial>
      <origin xyz="2.2383E-07 -0.010203 -0.013939" rpy="0 0 0" />
      <mass value="0.00086967" />
      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
    </inertial>
    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
  </link>
  <joint name="right_thumb_tip" type="fixed">
    <origin xyz="0 0.0059474 0.031823" rpy="0 0 0" />
    <parent link="right_thumb_distal_link" />
    <child link="right_thumb_tip_link" />
    <axis xyz="0 0 0" />
  </joint>
  <link name="right_index_proximal_link">
    <inertial>
      <origin xyz="4.30529992941076E-08 -0.0024559603959039 0.0191142514901699" rpy="0 0 0" />
      <mass value="0.00720026836301954" />
      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
    </inertial>
    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
  </link>
  <joint name="right_index_mcp_flex" type="revolute">
    <origin xyz="0.030626 -0.0011782 0.10542" rpy="0 0.05236 -0.034907" />
    <parent link="right_base_link" />
    <child link="right_index_proximal_link" />
    <axis xyz="1 0 0" />
    <limit lower="0" upper="1.5708" effort="0" velocity="0" />
  </joint>
  <link name="right_index_middle_link">
    <inertial>
      <origin xyz="-6.47985752902369E-09 -0.000363269614703799 0.00876079008757696" rpy="0 0 0" />
      <mass value="0.00276150356687874" />
      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
    </inertial>
    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
  </link>
  <joint name="right_index_pip" type="revolute">
    <origin xyz="0 -0.0014554 0.043" rpy="0 0 0" />
    <parent link="right_index_proximal_link" />
    <child link="right_index_middle_link" />
    <axis xyz="1 0 0" />
    <limit lower="0" upper="1.5708" effort="0" velocity="0" />
  </joint>
  <link name="right_index_distal_link">
    <inertial>
      <origin xyz="3.34671961321059E-07 -0.00120224143694181 0.00777234707760652" rpy="0 0 0" />
      <mass value="0.00183663667769987" />
      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

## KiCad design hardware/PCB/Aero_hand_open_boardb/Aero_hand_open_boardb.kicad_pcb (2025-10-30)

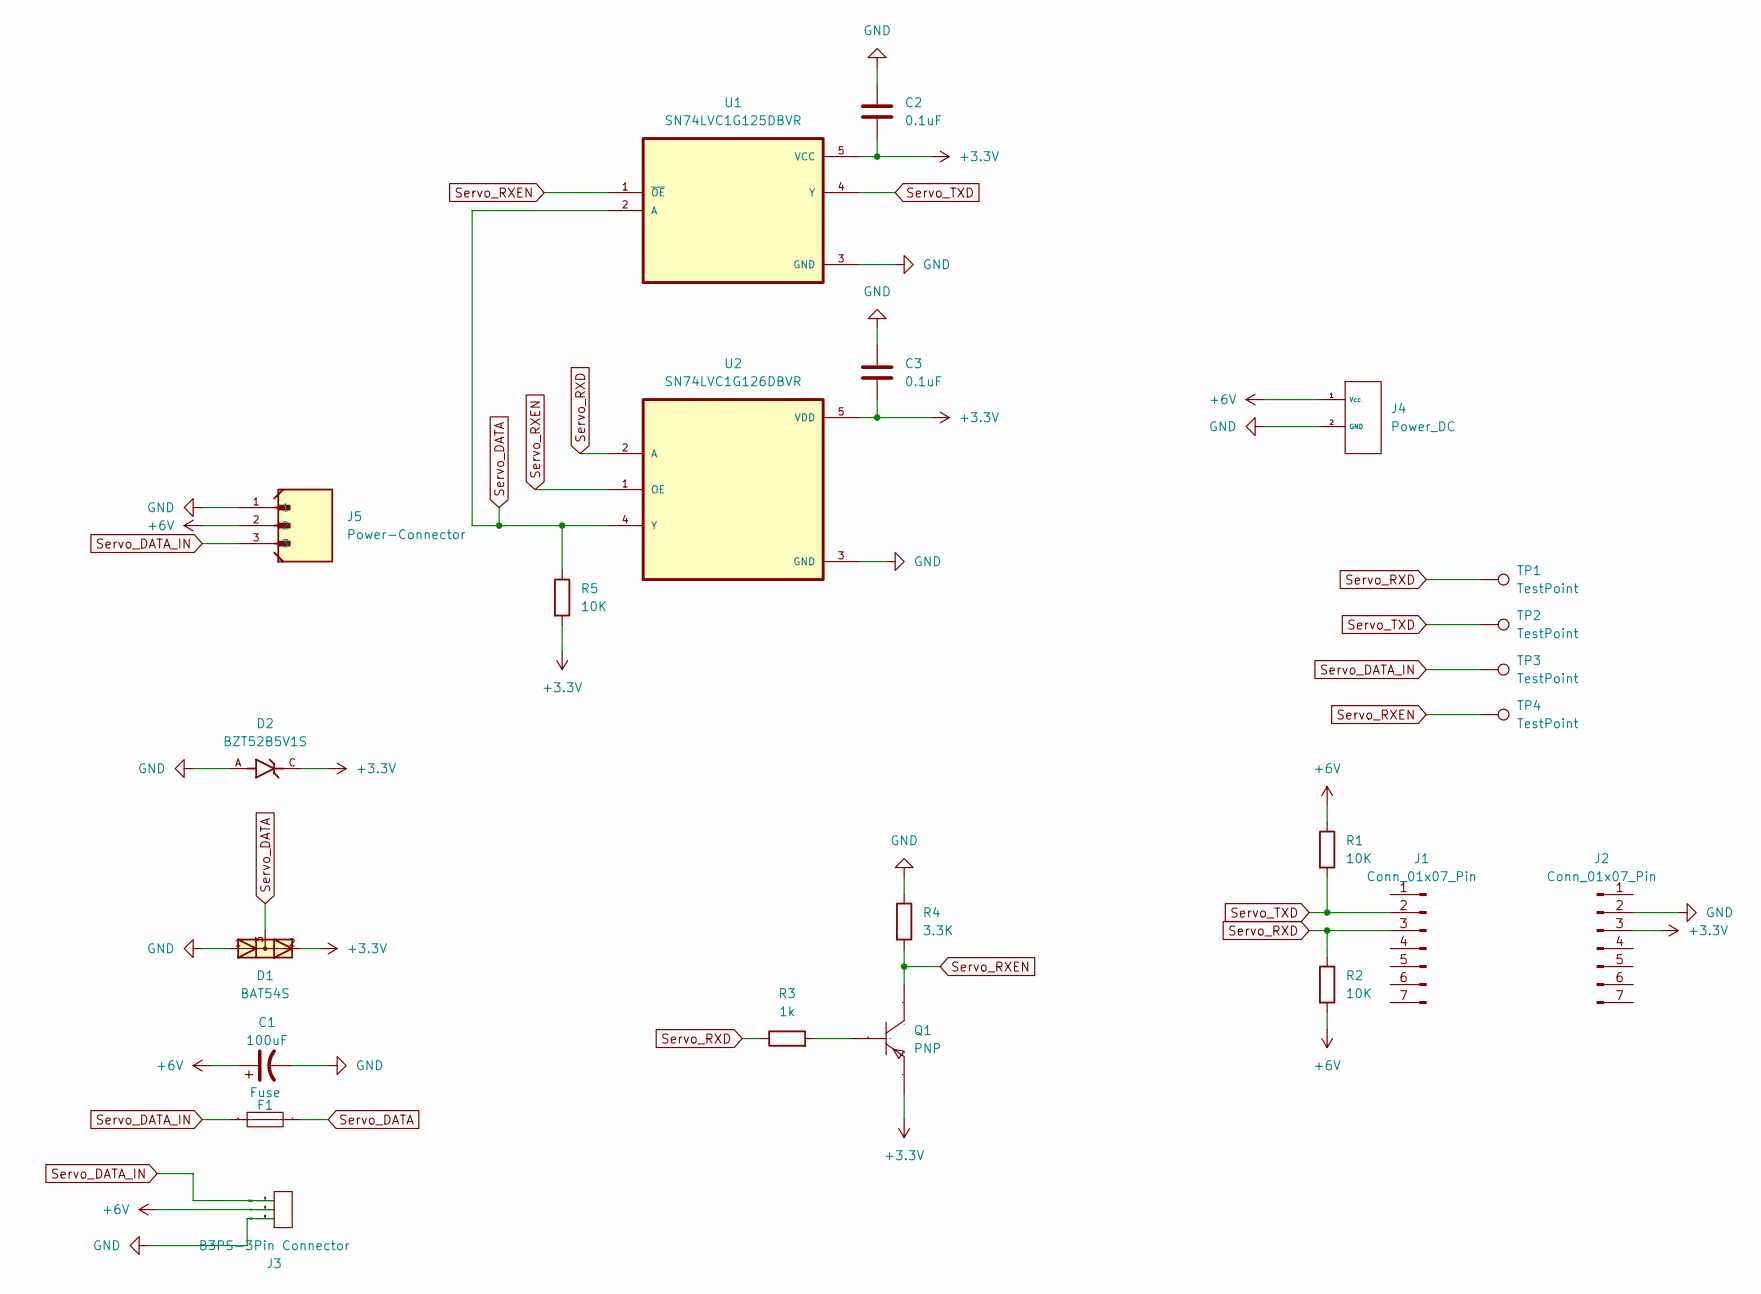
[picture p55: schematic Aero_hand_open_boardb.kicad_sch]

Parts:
C1: 100uF; CP_Radial_D5.0mm_P2.00mm
C2, C3: 0.1uF; C_0805
D1: BAT54S; SOT23
D2: BZT52B5V1S; DIO_BZT52B5V1S; PARTREV H2212
F1: Fuse; F0603; Manufacturer Part BSMD0603-010-24V; LCSC Part Name 24V 100mA 0603自恢复
J1, J2: Conn_01x07_Pin; PinHeader_1x07_P2.54mm_Vertical
J3: B3PS-3Pin Connector; JST S3P-VH(LF)(SN)
J4: Power_DC; KJ127-5.08
J5: Power-Connector; MOLEX_22057035; PARTREV A
Q1: PNP; SOT-23-3_L3.0-W1.7-P0.95-LS2.9-BR; Manufacturer Part MMBT2907A; LCSC Part Name MMBT2907A
R1, R2, R5: 10K; R_0805
R3: 1k; R_0805
R4: 3.3K; R_0805
TP1, TP2, TP3, TP4: TestPoint; TestPoint_Pad_D1.0mm
U1: SN74LVC1G125DBVR; SOT95P280X145-5N
U2: SN74LVC1G126DBVR; SOT95P280X145-5N; DigiKey_Part_Number 296-11605-1-ND

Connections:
+3.3V: C2.2, C3.2, D1.2, D2.C, J2.3, Q1.2 (E), R5.2, U1.5 (VCC), U2.5 (VDD)
+6V: C1.1, J3.2 (Vcc), J4.1 (Vcc), J5.2, R1.1, R2.2
GND: C1.2, C2.1, C3.1, D1.1, D2.A, J2.2, J3.1 (GND), J4.2 (GND), J5.1, R4.1, U1.3 (GND), U2.3 (GND)
unnamed: Q1.1 (B), R3.2
Servo_DATA: D1.3, F1.2, R5.1, U1.2 (A), U2.4 (Y)
Servo_DATA_IN: F1.1, J3.3 (Signal), J5.3, TP3.1
Servo_RXD: J1.3, R2.1, R3.1, TP1.1, U2.2 (A)
Servo_RXEN: Q1.3 (C), R4.2, TP4.1, U1.1 (~OE), U2.1 (OE)
Servo_TXD: J1.2, R1.2, TP2.1, U1.4 (Y)

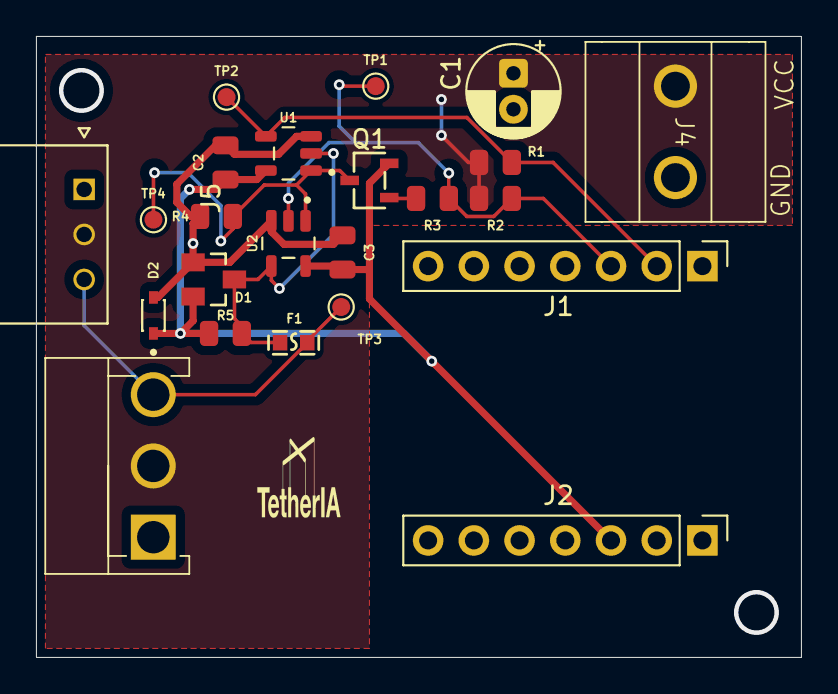
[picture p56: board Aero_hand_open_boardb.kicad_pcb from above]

Board: 2 copper layers, 42.5 x 34.5 mm, 23 parts (1 on the bottom side), 9 nets.

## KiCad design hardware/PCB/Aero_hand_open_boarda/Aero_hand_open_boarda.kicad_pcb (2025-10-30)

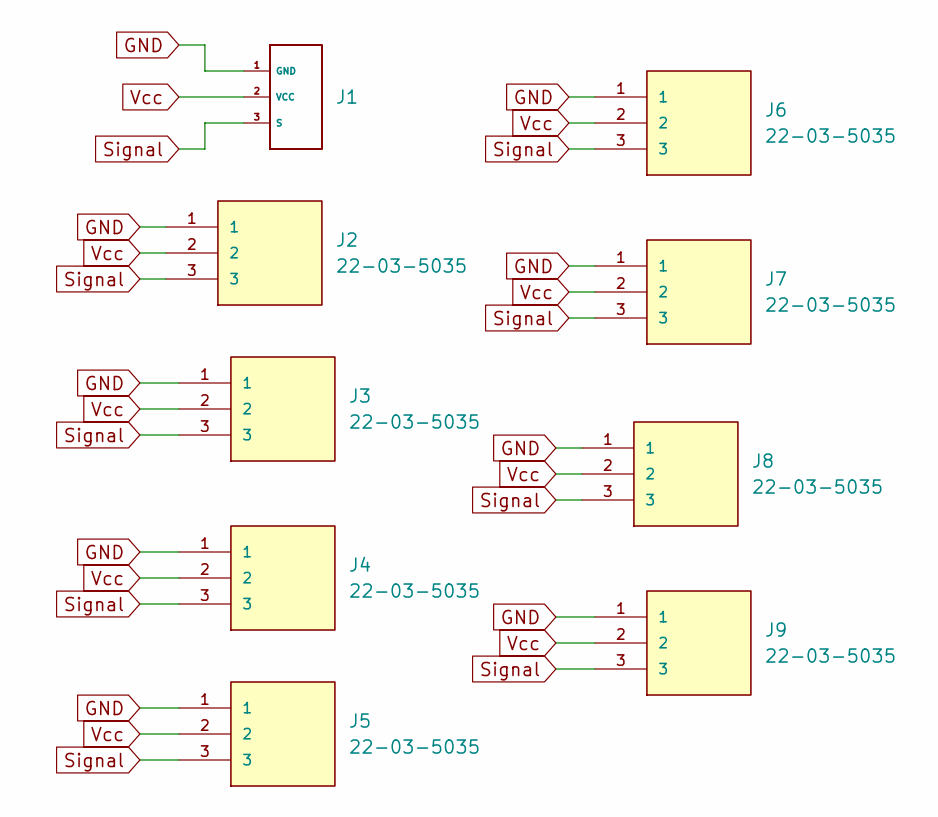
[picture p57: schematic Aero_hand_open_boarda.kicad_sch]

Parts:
J1: JST S3P-VH(LF)(SN)
J2, J3, J4, J5, J6, J7, J8, J9: 22-03-5035; MOLEX_22-03-5035; PARTREV B

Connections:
GND: J1.1 (GND), J2.1, J3.1, J4.1, J5.1, J6.1, J7.1, J8.1, J9.1
Signal: J1.3 (S), J2.3, J3.3, J4.3, J5.3, J6.3, J7.3, J8.3, J9.3
Vcc: J1.2 (VCC), J2.2, J3.2, J4.2, J5.2, J6.2, J7.2, J8.2, J9.2

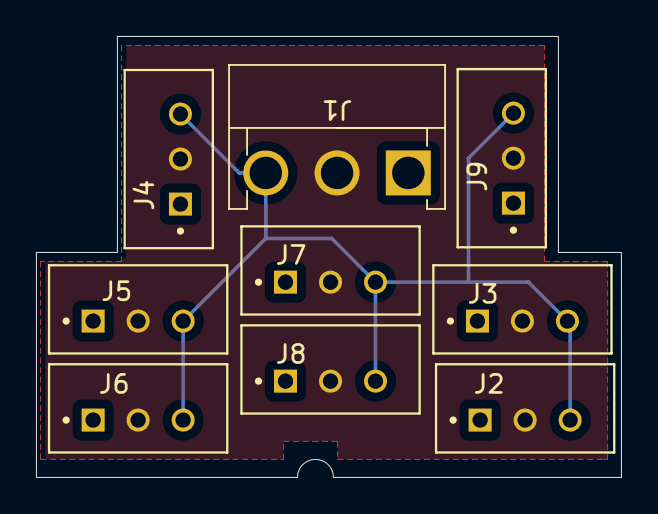
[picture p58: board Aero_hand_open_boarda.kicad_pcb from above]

Board: 2 copper layers, 32.5 x 24.5 mm, 9 parts (0 on the bottom side), 3 nets.

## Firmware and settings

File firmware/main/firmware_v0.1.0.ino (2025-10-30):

// TetherIA - Open Source Hand
// Aero Hand Firmware Source Code
#include <Arduino.h>
#include <Wire.h>
#include <HLSCL.h>
#include <Preferences.h>
#include "HandConfig.h"
#include "Homing.h"

HLSCL hlscl;
Preferences prefs;

// ---- UART pins to the servo bus (ESP32-S3 XIAO: RX=2, TX=3) ----
#define SERIAL2_TX_PIN 3
#define SERIAL2_RX_PIN 2

// ---- Servo IDs (declare at top) ----
const uint8_t SERVO_IDS[7] = { 0, 1, 2, 5, 8, 11, 14 };

ServoData sd[7];

// ---- Constants for Control Code byte ----
static const uint8_t HOMING    = 0x01;
static const uint8_t SET_ID    = 0x02;
static const uint8_t TRIM      = 0x03;
static const uint8_t CTRL_POS  = 0x11;
static const uint8_t CTRL_TOR  = 0x12;
static const uint8_t GET_POS   = 0x22;
static const uint8_t GET_VEL   = 0x23;
static const uint8_t GET_CURR  = 0x24;
static const uint8_t GET_TEMP  = 0x25;
static const uint8_t SET_SPE   = 0x31;
static const uint8_t SET_TOR   = 0x32;

// ---- Defaults for SyncWritePosEx ----
static uint16_t g_speed[7]  = {32766,32766,32766,32766,32766,32766,32766};
static uint8_t  g_accel[7]  = {0,0,0,0,0,0,0};     // 0..255
static uint16_t g_torque[7] = {1023,1023,1023,1023,1023,1023,1023};

// ----- Registers / constants (Mapped as per Feetech Servo HLS3606M) -----
#define REG_ID                 0x05       // ID register
#define REG_CURRENT_LIMIT      28         // decimal address (word)
#define BROADCAST_ID           0xFE
#define SCAN_MIN               0
#define SCAN_MAX               253
#define REG_BLOCK_LEN          15
#define REG_BLOCK_START        56

// ----- Structure for the Metrics of Servo -------
struct ServoMetrics {
  uint16_t pos[7];
  uint16_t vel[7];
  uint16_t cur[7];
  uint16_t tmp[7];
};
static ServoMetrics gMetrics;

// -------- Global Control Mode State  ---------
enum ControlMode{
  MODE_POS=0,
  MODE_TORQUE=2
};
static ControlMode g_currentMode = MODE_POS;

// ----- Semaphores for Metrics and Bus for acquiring lock and release it -----
static SemaphoreHandle_t gMetricsMux;
SemaphoreHandle_t gBusMux = nullptr;

// ----- Homing module API Calls (provided below as .h/.cpp) --------
bool HOMING_isBusy();
void HOMING_start();

// ---- Set-ID helpers for setting ID ---
extern void runReIdScanAndSet(uint8_t Id, uint16_t currentLimit);
static volatile int g_lastFoundId; 

// ----- Helper Functions for Set-ID Mode -----
static bool scanRequireSingleServo(uint8_t* outId, uint8_t requestedNewId) {
  uint8_t first = 0xFF;
  int count = 0;
  if (gBusMux) xSemaphoreTake(gBusMux, portMAX_DELAY);
  for (int id = SCAN_MIN; id <= SCAN_MAX; ++id) {
    if (id == BROADCAST_ID) continue;        
    (void)hlscl.Ping((uint8_t)id);
    if (!hlscl.getLastError()) {
      if (count == 0) first = (uint8_t)id;
      ++count;
      if (count > 1) break;                    
    }
  }
  if (gBusMux) xSemaphoreGive(gBusMux);
  if (count == 1) {
    if (outId) *outId = first;
    return true;
  }
  if (count == 0) {
    uint8_t ack6[6] = { 0xFF, 0x00, requestedNewId, 0x00, 0x00, 0x00 };
    sendAckFrame(SET_ID, ack6, sizeof(ack6));
    return false;
  }
  uint8_t ack14[14] = {0xFF, 0xFF, 0xFF, 0xFF, 0xFF, 0xFF, 0xFF, 0xFF, 0x00, 0x00, 0x00, 0x00, 0x00, 0x00};
  sendAckFrame(SET_ID, ack14, sizeof(ack14));
  return false;
}
static void sendSetIdAck(uint8_t oldId, uint8_t newId, uint16_t curLimitWord) {
  uint16_t vals[7] = {0};
  vals[0] = oldId;
  vals[1] = newId;
  vals[2] = curLimitWord;
  uint8_t out[2 + 7*2];
  out[0] = SET_ID;  // 0x03
  out[1] = 0x00;    // filler
  for (int i = 0; i < 7; ++i) {
    out[2 + 2*i + 0] = (uint8_t)(vals[i] & 0xFF);
    out[2 + 2*i + 1] = (uint8_t)((vals[i] >> 8) & 0xFF);
  }
  Serial.write(out, sizeof(out));
}
// ---- Helper function to save and loadManual extends from NVS ------
static void loadManualExtendsFromNVS() {
  prefs.begin("hand", true);  // read-only
  for (uint8_t i = 0; i < 7; ++i) {
    String key = "ext" + String(i);
    int v = prefs.getInt(key.c_str(), -1);
    if (v >= 0 && v <= 4095) {
      sd[i].extend_count = v;
    }
  }
}
static void saveExtendsToNVS() {
  prefs.begin("hand", false);  // RW
  for (uint8_t i = 0; i < 7; ++i) {
    String kext = "ext" + String(i);
    prefs.putInt(kext.c_str(), (int)sd[i].extend_count);
  }
  prefs.end();
}

// ---- Helper function  for raw to U16 and U16 to raw ----
static inline uint16_t mapRawToU16(uint8_t channel, uint16_t raw) {
  int32_t ext  = sd[channel].extend_count;
  int32_t gra  = sd[channel].grasp_count;
  int32_t span = gra - ext;
  if (span == 0) return 0;  // avoid divide-by-zero
  int32_t val = ((int32_t)(raw - ext) * 65535L) / span;
  //Clamp
  if (val < 0) val = 0;
  if (val > 65535) val = 65535;
  return (uint16_t)val;
}
static inline uint16_t mapU16ToRaw(uint8_t channel, uint16_t u16) {
  int32_t ext = sd[channel].extend_count;
  int32_t gra = sd[channel].grasp_count;
  int32_t raw32;
  if (ext == 0 && gra == 0) {
    raw32 = ((uint64_t)u16 * 4095u) / 65535u;
  } else {
    raw32 = ext + ((int64_t)u16 * (gra - ext)) / 65535LL;
  }
  // clamp
  if (raw32 < 0)    raw32 = 0;
  if (raw32 > 4095) raw32 = 4095;
  return (uint16_t)raw32;
}

// ---- Helper Functions for u16, Decode to sign and copy values in u16 format----
static inline uint16_t leu_u16(const uint8_t *p) {
  return (uint16_t)p[0] | ((uint16_t)p[1] << 8);
}
static inline int16_t decode_signmag15(uint8_t lo, uint8_t hi) {
  uint16_t mag = ((uint16_t)(hi & 0x7F) << 8) | lo;  // 15-bit magnitude
  return (hi & 0x80) ? -(int16_t)mag : (int16_t)mag;
}
static inline void copy7_u16(uint16_t dst[7], const uint16_t src[7]) {
  for (int i = 0; i < 7; ++i) dst[i] = src[i];
}

// ----- Helper function to send u16 frame for POS,SPD,VEL,CURR and sendACK Packet ----
static inline void sendU16Frame(uint8_t header, const uint16_t data[7]) {
  uint8_t out[2 + 7*2];
  out[0] = header;
  out[1] = 0x00; // filler
  for (int i = 0; i < 7; ++i) {
    out[2 + 2*i + 0] = (uint8_t)(data[i] & 0xFF);
    out[2 + 2*i + 1] = (uint8_t)((data[i] >> 8) & 0xFF);
  }
  Serial.write(out, sizeof(out)); 
}
static inline void sendAckFrame(uint8_t header, const uint8_t* payload, size_t n) {
  uint8_t out[16];
  out[0] = header;
  out[1] = 0x00; // filler
  memset(out + 2, 0, 14);
  if (payload && n) {
    if (n > 14) n = 14;
    memcpy(out + 2, payload, n);
  }
  Serial.write(out, sizeof(out));
}

// ----- Functions to Send POS, VEL, CURR, TEMP -----
void sendPositions() {
  uint16_t buf[7];
  xSemaphoreTake(gMetricsMux, portMAX_DELAY);
  copy7_u16(buf, gMetrics.pos);
  xSemaphoreGive(gMetricsMux);
  sendU16Frame(GET_POS, buf);
}
void sendVelocities() {
  uint16_t buf[7];
  xSemaphoreTake(gMetricsMux, portMAX_DELAY);
  copy7_u16(buf, gMetrics.vel);
  xSemaphoreGive(gMetricsMux);
  sendU16Frame(GET_VEL, buf);
}
void sendCurrents() {
  uint16_t buf[7];
  xSemaphoreTake(gMetricsMux, portMAX_DELAY);
  copy7_u16(buf, gMetrics.cur);
  xSemaphoreGive(gMetricsMux);
  sendU16Frame(GET_CURR, buf);
}
void sendTemps() {
  uint16_t buf[7];
  xSemaphoreTake(gMetricsMux, portMAX_DELAY);
  copy7_u16(buf, gMetrics.tmp);
  xSemaphoreGive(gMetricsMux);
  sendU16Frame(GET_TEMP, buf);
}

// ----- Task - Sync Read running always on Core 1 ----- 
static void TaskSyncRead_Core1(void *arg) {
  uint8_t  rx[REG_BLOCK_LEN];          // 15 bytes
  uint16_t pos[7], vel[7], cur[7], tmp[7];
  const TickType_t period = pdMS_TO_TICKS(10);   // Change Frequency of Running here, 5 -200 Hz, 10-100 Hz, 20 -50 Hz
  TickType_t nextWake = xTaskGetTickCount();
  for (;;) {
    // try-lock: if control is using the bus, skip this cycle
    if (gBusMux && xSemaphoreTake(gBusMux, 0) != pdTRUE) {
      vTaskDelayUntil(&nextWake, period);
      continue;
    }
    bool ok = true;
    // one TX for the whole group (15-byte slice)
    hlscl.syncReadPacketTx((uint8_t*)SERVO_IDS, 7, REG_BLOCK_START, REG_BLOCK_LEN);
    for (uint8_t i = 0; i < 7; ++i) {
      if (!hlscl.syncReadPacketRx(SERVO_IDS[i], rx)) { ok = false; break; }
      uint16_t raw = leu_u16(&rx[0]);
      pos[i] = mapRawToU16(i, raw);                     // Position (unsigned)
      vel[i] = decode_signmag15(rx[2], rx[3]);                  // velocity (signed)
      tmp[i] = rx[7];                                           // temperature (unsigned, 1 byte)
      cur[i] = decode_signmag15(rx[13], rx[14]);                // current (signed)
      //vTaskDelay(1);
    }
    if (gBusMux) xSemaphoreGive(gBusMux);
    if (ok) {
      xSemaphoreTake(gMetricsMux, portMAX_DELAY);
      for (int i = 0; i < 7; ++i) {
        gMetrics.pos[i] = pos[i];
        gMetrics.vel[i] = vel[i];
        gMetrics.tmp[i] = tmp[i];
        gMetrics.cur[i] = cur[i];
      }
      xSemaphoreGive(gMetricsMux);
    } 
    vTaskDelayUntil(&nextWake, period);
  }
}
//Set-ID and Trim Servo functions
static bool handleSetIdCmd(const uint8_t* payload) {
  // Parse request: two u16 words, little-endian
  uint16_t w0 = (uint16_t)payload[0] | ((uint16_t)payload[1] << 8); // newId in low byte
  uint16_t w1 = (uint16_t)payload[2] | ((uint16_t)payload[3] << 8); // requested current limit
  uint8_t  newId    = (uint8_t)(w0 & 0xFF);
  uint16_t reqLimit = (w1 > 1023) ? 1023 : w1;
  // Invalid newId → ACK with oldId=0xFF, newId, cur=0
  if (newId > 253 || newId ==BROADCAST_ID) {
    uint8_t ack[6] = { 0xFF, 0x00, newId, 0x00, 0x00, 0x00 };
    sendAckFrame(SET_ID, ack, sizeof(ack));
    return true;
  }
  // Find any servo present
  uint8_t oldId = 0xFF;
  if (!scanRequireSingleServo(&oldId, newId)) return true; 
  
  if (newId != oldId) {
  if (gBusMux) xSemaphoreTake(gBusMux, portMAX_DELAY);
  (void)hlscl.Ping(newId);
  bool taken = !hlscl.getLastError();
  if (gBusMux) xSemaphoreGive(gBusMux);
  if (taken) {
    uint8_t ack14[14] = { oldId, 0x00, newId, 0x00, 0x00, 0x00, 0x00, 0x00, 0x00, 0x00, 0x00, 0x00, 0x00, 0x00};
    sendAckFrame(SET_ID, ack14, sizeof(ack14));
    return true;
  }
  }
  if (gBusMux) xSemaphoreTake(gBusMux, portMAX_DELAY);
  (void)hlscl.unLockEprom(oldId);
  (void)hlscl.writeWord(oldId, REG_CURRENT_LIMIT, reqLimit);
  uint8_t targetId = oldId;
  if (newId != oldId) {
    (void)hlscl.writeByte(oldId, REG_ID, newId);   // REG_ID = 0x05
    targetId = newId;
  }
  (void)hlscl.LockEprom(targetId);
  
  // Read back limit for ACK
  uint16_t curLimitRead = 0;
  int rd = hlscl.readWord(targetId, REG_CURRENT_LIMIT);
  if (rd >= 0) curLimitRead = (uint16_t)rd;
  if (gBusMux) xSemaphoreGive(gBusMux);
  // Build 6-byte payload: oldId(LE16), newId(LE16), curLimit(LE16) and send
  uint8_t ack[6];
  ack[0] = oldId;                      // oldId lo
  ack[1] = 0x00;                       // oldId hi
  ack[2] = targetId;                   // newId lo
  ack[3] = 0x00;                       // newId hi
  ack[4] = (uint8_t)(curLimitRead & 0xFF);
  ack[5] = (uint8_t)((curLimitRead >> 8) & 0xFF);
  sendAckFrame(SET_ID, ack, sizeof(ack));
  return true;
}
static bool handleTrimCmd(const uint8_t* payload) {
  // Parse little-endian fields
  uint16_t rawCh  = (uint16_t)payload[0] | ((uint16_t)payload[1] << 8);
  uint16_t rawDeg = (uint16_t)payload[2] | ((uint16_t)payload[3] << 8);
  int      ch      = (int)rawCh;         // 0..6
  int16_t  degrees = (int16_t)rawDeg;    // signed degrees
  // Validate channel (0..6)
  if (ch < 0 || ch >= 7) {
    // Optionally send a NACK or silent-accept to preserve framing
    return true;
  }
  // Degrees -> counts (≈11.375 counts/deg), clamp to 0..4095
  int delta_counts = (int)((float)degrees * 11.375f);
  int new_ext = (int)sd[ch].extend_count + delta_counts;
  if (new_ext < 0)    new_ext = 0;
  if (new_ext > 4095) new_ext = 4095;
  sd[ch].extend_count = (uint16_t)new_ext;
  // Persist to NVS
  prefs.begin("hand", false);
  prefs.putInt(String("ext" + String(ch)).c_str(), sd[ch].extend_count);
  prefs.end();
  // ACK payload: ch (u16, LE), extend_count (u16, LE)
  uint8_t ack[4];
  ack[0] = (uint8_t)(ch & 0xFF);
  ack[1] = (uint8_t)((ch >> 8) & 0xFF);
  ack[2] = (uint8_t)(sd[ch].extend_count & 0xFF);
  ack[3] = (uint8_t)((sd[ch].extend_count >> 8) & 0xFF);
  sendAckFrame(TRIM, ack, sizeof(ack));   // 16 bytes on the wire
  return true;
}
static bool handleSetSpeedCmd(const uint8_t* payload)
{
  uint16_t rawId = (uint16_t)payload[0] | ((uint16_t)payload[1] << 8);
  uint16_t rawSpd = (uint16_t)payload[2] | ((uint16_t)payload[3] << 8);
  if (rawId >= 7) {
    //invalid index of servo actuator - So give error code (0–6 valid)
    uint8_t ack[4] = {0xFF, 0xFF, 0x00, 0x00};
    sendAckFrame(SET_SPE, ack, sizeof(ack));
    return true;
  }
  if (rawSpd > 32766) rawSpd = 32766;  // clamp
  g_speed[rawId] = rawSpd;
  // ACK back: servo id and speed
  uint8_t ack[4];
  ack[0] = (uint8_t)(rawId & 0xFF);
  ack[1] = (uint8_t)((rawId >> 8) & 0xFF);
  ack[2] = (uint8_t)(rawSpd & 0xFF);
  ack[3] = (uint8_t)((rawSpd >> 8) & 0xFF);
  sendAckFrame(SET_SPE, ack, sizeof(ack));
  return true;
}
static bool handleSetTorCmd(const uint8_t* payload)
{
  uint16_t rawId = (uint16_t)payload[0] | ((uint16_t)payload[1] << 8);
  uint16_t rawTor = (uint16_t)payload[2] | ((uint16_t)payload[3] << 8);
  // Validate ID range (0..6)
  if (rawId >= 7) {
    uint8_t ack[4] = {0xFF, 0xFF, 0x00, 0x00};  // invalid ID ack
    sendAckFrame(SET_TOR, ack, sizeof(ack));
    return true;
  }
  if (rawTor > 1023) rawTor = 1023;
  // Update the per-servo torque value
  g_torque[rawId] = rawTor;
  uint8_t ack[4];
  ack[0] = (uint8_t)(rawId & 0xFF);
  ack[1] = (uint8_t)((rawId >> 8) & 0xFF);
  ack[2] = (uint8_t)(rawTor & 0xFF);
  ack[3] = (uint8_t)((rawTor >> 8) & 0xFF);
  sendAckFrame(SET_TOR, ack, sizeof(ack));
  return true;
}

// ----- Returns true if a valid 16-byte frame was consumed and handled -----
static bool handleHostFrame(uint8_t op) {
  // Wait until full frame is buffered: filler + 14 payload
  while (Serial.available() < 15) { /* wait */ }
  uint8_t buf[15];
  for (int i = 0; i < 15; ++i) {
    int ch = Serial.read(); if (ch < 0) return false;
    buf[i] = (uint8_t)ch;
  }
  const uint8_t* payload = &buf[1]; // buf[0] = filler 0x00 (ignored)

  switch (op) {
    case CTRL_POS: {
      int16_t pos[7];
      for (int i = 0; i < 7; ++i) {
        uint16_t u16 = (uint16_t)payload[2*i] | ((uint16_t)payload[2*i+1] << 8);
        pos[i] = mapU16ToRaw(i, u16);
      }
      if (gBusMux) xSemaphoreTake(gBusMux, portMAX_DELAY);
      if (g_currentMode != MODE_POS) {
        for (int i = 0; i < 7; ++i) {
          uint8_t id = SERVO_IDS[i];
          hlscl.ServoMode(id);
        }
        g_currentMode = MODE_POS;
      }
      hlscl.SyncWritePosEx((uint8_t*)SERVO_IDS, 7, pos, g_speed, g_accel, g_torque);
      if (gBusMux) xSemaphoreGive(gBusMux);
      return true;
    }

    case CTRL_TOR: {
      int16_t torque_cmd[7];
      for (int i = 0; i < 7; ++i) {
        uint16_t mag = (uint16_t)payload[2*i] | ((uint16_t)payload[2*i + 1] << 8);
        if (mag > 1000) mag = 1000;
        uint8_t ch = SERVO_IDS[i];
        int sgn = (sd[ch].extend_count > sd[ch].grasp_count) ? +1 : -1;
        if (sd[ch].extend_count == sd[ch].grasp_count) sgn = +1;
        torque_cmd[i] = (int16_t)(sgn * (int)mag);
      }
      if (gBusMux) xSemaphoreTake(gBusMux, portMAX_DELAY);
      if (g_currentMode != MODE_TORQUE) {
        for (int i = 0; i < 7; ++i) {
          uint8_t id = SERVO_IDS[i];
          hlscl.EleMode(id);
        }
        g_currentMode = MODE_TORQUE;
      }
      for (int i = 0; i < 7; ++i) {
        uint8_t id = SERVO_IDS[i];
        hlscl.WriteEle(id, torque_cmd[i]);
      }
      if (gBusMux) xSemaphoreGive(gBusMux);
      return true;
    }

    case SET_TOR: {
      return handleSetTorCmd(payload);
    }

    case SET_SPE: {
      return handleSetSpeedCmd(payload);
    }

    case HOMING: {
      HOMING_start();   // blocks
      saveExtendsToNVS();
      sendAckFrame(HOMING, nullptr, 0);
      return true;
    }

    case SET_ID: {
      return handleSetIdCmd(payload);
    }

    case TRIM: {
      return handleTrimCmd(payload);
    }

    case GET_POS: {
      sendPositions();
      return true;
    }

    case GET_VEL: {
      sendVelocities();
      return true;
    }

    case GET_TEMP: {
      sendTemps();
      return true;
    }

    case GET_CURR: {
      sendCurrents();
      return true;
    }

    default:
      //Unknown Control Code — consume frame to preserve alignment
      return true;
  }
}

void setup() {
  // USB debug
  Serial.begin(921600);
  delay(100);

  // Servo bus UART @ 1 Mbps
  Serial2.begin(1000000, SERIAL_8N1, SERIAL2_RX_PIN, SERIAL2_TX_PIN);
  hlscl.pSerial = &Serial2;

  resetSdToBaseline();
  prefs.begin("hand", false);
  loadManualExtendsFromNVS();
  #if defined(LEFT_HAND)
    Serial.println("[BOOT] Hand Type: LEFT_HAND");
  #elif defined(RIGHT_HAND)
    Serial.println("[BOOT] Hand Type: RIGHT_HAND");
  #else
    Serial.println("[BOOT] Hand Type: UNKNOWN");
  #endif
  // ---- Presence Check on Every Boot -----
  Serial.println("\n[Init] Pinging servos...");
  for (uint8_t i = 0; i < 7; ++i) {
    uint8_t id = SERVO_IDS[i];
    int resp = hlscl.Ping(id);
    if (!hlscl.getLastError()) {
      Serial.print("  ID "); Serial.print(id); Serial.println(": OK");
    } else {
      Serial.print("  ID "); Serial.print(id); Serial.println(": NO REPLY");
    }
  }
  //Syncreadbegin to Start the syncread
  hlscl.syncReadBegin(sizeof(SERVO_IDS), REG_BLOCK_LEN, /*rx_fix*/ 8);

  for (int i = 0; i < 7; ++i){
  Serial.printf("Servo %d dir=%d\n", i, sd[i].servo_direction);}
  //Initialisation of Mutex and Task serial pinned to Core 1
  gBusMux =xSemaphoreCreateMutex();
  gMetricsMux = xSemaphoreCreateMutex();
  xTaskCreatePinnedToCore(TaskSyncRead_Core1, "SyncRead", 4096, NULL, 1, NULL, 1); // run on Core1
}

void loop() {
  static uint32_t last_cmd_ms = 0; 

  // Gate all host input during homing
  if (HOMING_isBusy()) {
    while (Serial.available()) { Serial.read(); }
    vTaskDelay(pdMS_TO_TICKS(5));
    return;
  }

  // Process exactly one complete 16-byte frame when available
  if (Serial.available() >= 16) {
    int op = Serial.read();
    if (op >= 0) {
      if (handleHostFrame((uint8_t)op)) {
        last_cmd_ms = millis();
        return;
      }
    }
  }
}

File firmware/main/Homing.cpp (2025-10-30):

#include "Homing.h"
#include "HandConfig.h"

// ----------------------- Immutable baselines -----------------------
// Always define both symbols so linker can resolve them
const ServoData sd_base_left[7] = {
  {3186,2048,1},{2048,865,-1},{0,2980,1},{4095,817,-1},{4095,817,-1},{4095,817,-1},{4095,817,-1},
};
const ServoData sd_base_right[7] = {
  {910,2048,-1},{2048,3231,1},{4095,1115,-1},{0,3278,1},{0,3278,1},{0,3278,1},{0,3278,1},
};

// ----------------------- Utilities -----------------------
void resetSdToBaseline() {
#if defined(RIGHT_HAND)
  const ServoData* src = sd_base_right;
#elif defined(LEFT_HAND)
  const ServoData* src = sd_base_left;
#else
  #warning "No hand macro defined; defaulting to RIGHT_HAND baseline"
  const ServoData* src = sd_base_right;
#endif
  for (int i = 0; i < 7; ++i) sd[i] = src[i];
}

// ----------------------- Busy flag & homing core -----------------------
static volatile bool s_busy = false;
bool HOMING_isBusy() { return s_busy; }

static void zero_with_current(uint8_t channel, uint8_t servoID, int direction, int current_limit) {
  int current = 0;
  int position = 0;
  hlscl.ServoMode(servoID);
  hlscl.FeedBack(servoID);
  uint32_t t0 = millis();
  while (abs(current) < current_limit) {
    hlscl.WritePosEx(servoID, 50000 * direction, 10, 10, current_limit);
    current  = hlscl.ReadCurrent(servoID);
    position = hlscl.ReadPos(servoID);
    if (millis() - t0 > 25000) break; 
    vTaskDelay(pdMS_TO_TICKS(1));
  }
  // Primary calibration at contact
  hlscl.WritePosEx(servoID, position, 60, 50, 1000);
  delay(30);
  hlscl.CalibrationOfs(servoID);
  delay(50);
  position = hlscl.ReadPos(servoID);

  if (channel == 0) {
    // Thumb abduction: hold grasp posture for a moment
    hlscl.WritePosEx(servoID, sd[channel].grasp_count, 60, 50, 500);
    delay(2000);
  } else if (channel == 1) {
    // Thumb flexion: go to extend
    hlscl.WritePosEx(servoID, sd[channel].extend_count, 60, 50, 500);
    delay(1000);
  } else if (channel == 2) {
    // Thumb tendon: nudge and recalibrate, then extend
    hlscl.WritePosEx(servoID, position + (direction * 2048), 60, 50, 500);
    delay(1500);
    hlscl.CalibrationOfs(servoID);
    delay(500);
    hlscl.WritePosEx(servoID, sd[channel].extend_count, 60, 50, 500);
    delay(1000);
  } else {
    // Fingers: nudge and recalibrate, then extend
    hlscl.WritePosEx(servoID, position + (direction * 2048), 60, 50, 500);
    delay(1500);
    hlscl.CalibrationOfs(servoID);
    delay(500);
    hlscl.WritePosEx(servoID, sd[channel].extend_count, 60, 50, 500);
    delay(1000);
  }
}

void zero_all_motors() {
  resetSdToBaseline();
  if (gBusMux) xSemaphoreTake(gBusMux, portMAX_DELAY);
  zero_with_current(SERVO_IDS[0],  sd[0].servo_direction, 750);   // Thumb Abduction
  zero_with_current(SERVO_IDS[1],  sd[1].servo_direction, 950);   // Thumb Flex
  zero_with_current(SERVO_IDS[2],  sd[2].servo_direction, 950);   // Thumb Tendon
  zero_with_current(SERVO_IDS[3],  sd[3].servo_direction, 950);   // Index
  zero_with_current(SERVO_IDS[4],  sd[4].servo_direction, 950);   // Middle
  zero_with_current(SERVO_IDS[5],  sd[5].servo_direction, 950);  // Ring
  zero_with_current(SERVO_IDS[6],  sd[6].servo_direction, 950);  // Pinky
  // Post-homing settling moves
  hlscl.WritePosEx(SERVO_IDS[0], sd[0].extend_count, 2400, 0, 1023);   // Thumb Abduction to extend
  hlscl.WritePosEx(SERVO_IDS[1], sd[1].extend_count, 2400, 0, 1023);   // Thumb Flexion to extend
  hlscl.WritePosEx(SERVO_IDS[2], sd[2].extend_count, 2400, 0, 1023);   // Thumb Tendon to extend
  hlscl.WritePosEx(SERVO_IDS[3], sd[3].extend_count, 2400, 0, 1023);   // Index to extend
  hlscl.WritePosEx(SERVO_IDS[4], sd[4].extend_count, 2400, 0, 1023);   // Middle to extend
  hlscl.WritePosEx(SERVO_IDS[5], sd[5].extend_count, 2400, 0, 1023);   // Ring to extend
  hlscl.WritePosEx(SERVO_IDS[6], sd[6].extend_count, 2400, 0, 1023);   // Pinky to extend
  if (gBusMux) xSemaphoreGive(gBusMux);
}

void HOMING_start() {
  s_busy = true;
  zero_all_motors();
  s_busy = false;
}

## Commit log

2025-10-14 Auto-sync/ind2mono-20251013-docs-only (#3)
    * Squashed 'docs/' changes from 1abafa3..bced288
    bced288 User/harsh/firmwaredoc (#13)
    3ee8637 add intro and assemble instruction and sidebar adjustment (#11)
    6b6a7fe shorten title
    8335dd7 find a replicate sentence
    d2932ee rewrite and focus on our hand
    2a55c0e add quick start
    9fb88e4 add hand sim page
    git-subtree-dir: docs
    git-subtree-split: bced2888bff529960f6fd48e08497e4c1eb436f0
    * doc imgs files
    ---------
2025-10-14 Update README.md (#7)
    updated weight and printing instructions
2025-10-17 add hardware readme file (#10)
    * add hardware readme file
    * 15 joints -> 16 joints
    * fix physical material
    * cable -> tendon
    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
2025-10-17 git subrepo clone --branch=public_release https://github.com/TetherIA/aero-open-ros2.git ros2 (#11)
    subrepo:
    subdir: "ros2"
    merged: "8c87f05"
    upstream:
    origin: "https://github.com/TetherIA/aero-open-ros2.git"
    branch: "public_release"
    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
    [aero_hand_open_right.urdf, right_base_link.STL, right_index_distal_link.STL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]
2025-10-27 FIX: Solving out of bounds error when uploading different servo IDs than default. The script now receives the channel ID and sends packets to the servo ID mapped by channelID == idx in servoID.
    [Homing.cpp, firmware_v0.1.0.ino]
2025-10-27 Manual sync: individual → monorepo 20251027 (#18)
    * git subrepo commit (merge) hardware
    subdir: "hardware"
    merged: "852004f"
    origin: "https://github.com/TetherIA/aero-open-hardware.git"
    branch: "main"
    commit: "71a4bfa"
    git-subrepo:
    version: "0.4.9"
    origin: "https://github.com/Homebrew/brew"
    commit: "3269773003"
    * fix(subrepo): update parent after squash/rebase to 2896c9db7bd4b1ec8009e6c9ddc9a11a534088ff
    * git subrepo pull --branch=main firmware
    subdir: "firmware"
    merged: "d7bd82e"
    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
    [100ufcap.stp, 22-03-5035.step, 22057035.step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]
2025-10-29 Revise README with new sections and links (#19)
    Updated the README to include new sections on mechanical, assembly, hardware setup, PCB, and firmware, along with relevant links.

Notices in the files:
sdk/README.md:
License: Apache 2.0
